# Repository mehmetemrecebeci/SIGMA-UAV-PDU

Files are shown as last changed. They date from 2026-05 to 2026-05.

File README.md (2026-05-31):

SIGMA UAV Power Distribution Unit (PDU), insansız hava araçlarında yüksek akım güç dağıtımını güvenli ve verimli şekilde gerçekleştirmek amacıyla geliştirilen çok katmanlı bir PCB tasarım projesidir. Tasarım sürecinde Altium Designer kullanılarak güç bütünlüğü, akım dönüş yolları ve elektromanyetik girişim (EMI) gereksinimleri dikkate alınmıştır.

Kart mimarisi; 24V, 12V, 9V ve 5V olmak üzere çoklu güç raylarından oluşmakta olup ESC'ler, servo sistemleri, görev bilgisayarları ve uçuş elektroniği için ayrılmış güç dağıtım altyapısı sağlamaktadır. Güç ve sinyal katmanları ayrıştırılarak düşük empedanslı akım yolları oluşturulmuş, sistem kararlılığı ve gürültü bağışıklığı artırılmıştır.

Proje kapsamında yüksek akım PCB yönlendirme teknikleri, geniş bakır alanlar, polygon tabanlı güç dağıtımı, via stitching uygulamaları ve çok katmanlı güç düzlemleri kullanılmıştır. Ayrıca güç dönüş akımlarının optimizasyonu, termal dağılım analizi ve EMI azaltma stratejileri üzerine çalışmalar gerçekleştirilmiştir.

Devam eden Rev2 geliştirme sürecinde tasarım, 6 katmanlı mimariye taşınarak güç dağıtım performansı, termal yönetim, EMI dayanımı ve üretilebilirlik kriterleri açısından iyileştirilmektedir.

Kullanılan Araçlar ve Teknolojiler:
• Altium Designer
• High Current PCB Design
• Power Distribution Architecture
• Multi-Rail Power Systems
• Grounding Strategy
• Power Integrity
• Thermal Design
• EMI/EMC Aware PCB Layout
• Via Stitching & Polygon Routing

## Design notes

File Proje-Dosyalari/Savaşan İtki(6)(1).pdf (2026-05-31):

Durumlar | Gereken T/W Oranı | Gerçeklşme Oranı | Gerçekleşme Süresi (dk) | Gereken Thrust | Harcanan Güç(W) | Harcanacak Toplam Güç (Wh) | Gereken Kapasite (mAh)
Cruise | 0.2 | 0.7 | 24.5 | 1300 | 166 | 67.78333333 | 3053.30
Maneuver | 0.5 | 0.2 | 7 | 3250 | 519 | 60.55 | 2727.48
High Effort | 1 | 0.1 | 3.5 | 6500 | 1364 | 79.56666667 | 3584.08
MTOW(g) | 6500 | | | | | İtki | 9364.86
Uçuş Süresi (dk) | 35 | | | | | İtki Güvenli | 11612.43243
Motor | Sunnysky x5220 KV380 X90 | | | | | Aviyonikler | 1102.083333
Bataryanın Nominal Voltajı(V) | 22.2 | | | | | Aviyonikler Güvenli | 1366.583333
Pervane Boyutu | 18*8 | | | | | Toplam | 10466.95
| | | | | | Toplam Güvenli | 12979.01577
Komponent | Komponent Adı | Ağırlık (Gram) | Maliyet
Motor | Sunnysky 5220 380KV | 486 | ₺11,560.00
İtki Bataryası | Profuse 15000mAh 15C 6S(solidstate) | 1065 | ₺17,000.00
Aviyonik Bataryası | Profuse 4200mAh 40C 2S | 234 | ₺1,774.00
İtki Batarya ESC | 120A ESC | 155 | ₺4,815.00
Aviyonik Batrya ESC | Hobbywing 8-15A ESC | 36 | ₺1,450.00
Pervane | 18*8 | 72 | ₺523.00
Toplam | | 1866 | ₺37,122.00

Aviyonik | Aviyoniğin Çalışmak İçin İhtiyaç Duyduğu Güç(W) | Wh | Volta j | Adet | Çekilecek Anlık Akım (A) | Görev Süresi(dk) | Toplam Kapasite
Pixhawk Cube Orange+ | 14 | 7 | 5 | 1 | 2.8 | 30 | 1400
RFD 868x | 2.5 | 1.25 | 5 | 1 | 1 | 30 | 500
R16F Alıcı | 0.25 | 0.125 | 5 | 1 | 0.05 | 30 | 25
Here 4 GPS | 3.33 | 1.665 | 5 | 1 | 0.666 | 30 | 333
Tf-mini plus Lidar | 0.05 | 0.025 | 5 | 1 | 0.11 | 30 | 55
mateksys ASPD-4525 | 0.3 | 0.15 | 6 | 1 | 0.05 | 30 | 25
Hitec HS-422 | 2 | 1 | 5 | 2 | 0.4 | 30 | 200
Emax ES08MD II | 5 | 2.5 | 5 | 5 | 1 | 30 | 500
Toplam Aviyonik | 27.43 | 13.715 | - | - | 6.076 | - | 3038
Toplam Aviyonik Güvenli | 3645.6
Arducam B0353 | 3 | 1.5 | 5 | 1 | 0.6 | 30 | 300
Jetson Orin NX 16 GB | 15 | 7.5 | 12 | 1 | 1.25 | 30 | 625
Ubiquiti Rocket 5AC LİTE | 8.5 | 4.25 | 24 | 1 | 0.354166667 | 30 | 177.0833333
Toplam İtki | 26.5 | 13.25 | - | - | 2.204166667 | 30 | 1102.083333
Toplam İtki Güvenli | 1366.583333

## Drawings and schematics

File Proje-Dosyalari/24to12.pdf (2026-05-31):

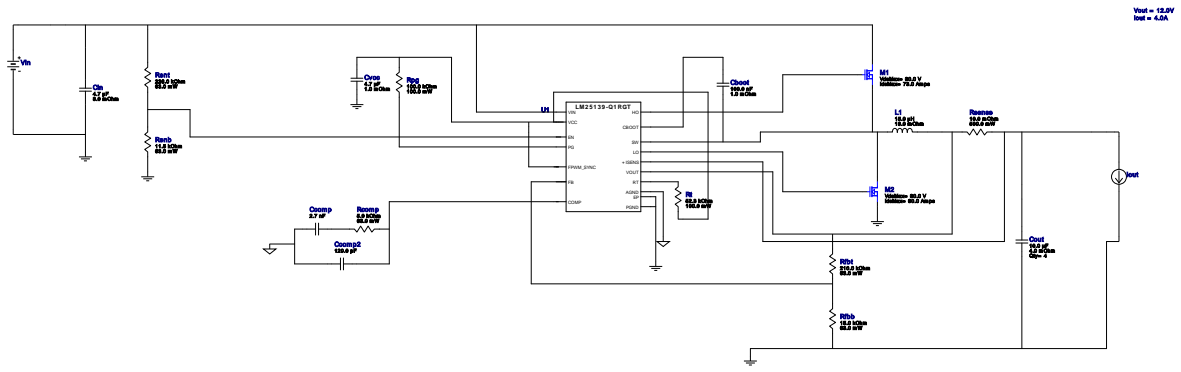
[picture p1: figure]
LM 2 5 1 3 9 -Q1 RGT VIN; FPWM_SYNC; AGND; COMP; VOUT; + ISENS; VCC; PGND; CBOOT EN; Cvcc 4.7 µF 1.0 m Ohm; Cout 10.0 µF; 4.0 m Ohm Qty= 4; Rpg 100.0 kOhm 100.0 m W; Rent 226.0 kOhm; Renb 11.5 kOhm 63.0 m W; M2 VdsMax= 30.0 V; IdsMax= 60.0 Am ps Rt 52.3 kOhm; 100.0 m W Ccom p; Rcom p; 5.9 kOhm 63.0 m W; Ccom p2 120.0 pF; Rfbb 15.0 kOhm 63.0 m W; Rfbt 210.0 kOhm; 19.0 m Ohm; Rsense; 10.0 m Ohm 500.0 m W; Vout = 12.0V Iout = 4.0A; Cin 4.7 µF 3.0 m Ohm; Cboot 100.0 nF; 1.0 m Ohm; M1 VdsMax= 30.0 V IdsMax= 73.0 Am ps; Vin; Iout

Copyright © 2026, Texas Instruments Incorporated | 1 | ti.com/webench

WEBENCH®
Design Report LM25139QRGTRQ1 : LM25139QRGTRQ1 23V-24V to 12.00V @ 4A March 28, 2026 08:51:25 GMT-05:00

## WEBENCH ® Design Report

Design : 13 LM25139QRGTRQ1
LM25139QRGTRQ1 23V-24V to 12.00V @ 4A

VinMin = 23.0V
VinMax = 24.0V
Vout = 12.0V
Iout = 4.0A

Device = LM25139QRGTRQ1
Topology = Buck
Created = 2026-03-28 08:48:47.775 BOM Cost = $2.57
BOM Count = 21
Total Pd = 1.12W

### Design Alerts

Component Selection Information
The LM25139-Q1 is qualified for Automotive applications. All passives and other components selected in this design may not be qualified for Automotive applications. The user is required to verify that all components in the design meet the qualification and safety requirements for their specific application.Please enter Enable UVLO Start Threshold greater than Enable 1.1* UVLO Stop Threshold. UVLO Start Threshold is assumed as 23.0V to avoid invalid results.

## Electrical BOM

Name | Manufacturer | Part Number | Properties | Qty Price | Footprint
Cboot | MuRata | GRM155R71A104KA01D (http://search.murata.co.jp/Ceramy/PnsearchViewAction.do) Series= X7R | Cap= 100.0 nF ESR= 1.0 mOhm VDC= 10.0 V IRMS= 0.0 A
1 | $0.01
| | | | | 0402 3 mm²
Ccomp | MuRata | GRM1885C1H272JA01J (http://www.murata.com/products/catalog/pdf/c02e.pdf) Series= C0G/NP0

Cap= 2.7 nF
VDC= 50.0 V
IRMS= 0.0 A

1 $0.02
0603 5 mm²
Ccomp2 | Taiyo Yuden | UMK105CG121JV-F (http://media.digikey.com/pdf/Data%20Sheets/Taiyo%20Yuden%20PDFs%20URL%20links/Standard%20Multilayer%20Ceramic%20Caps.pdf) Series= C0G/NP0

Cap= 120.0 pF
VDC= 50.0 V
IRMS= 0.0 A

1 $0.01
0402 3 mm²
Cin | MuRata | GRM31CR71H475KA12L (http://search.murata.co.jp/Ceramy/PnsearchViewAction.do) Series= X7R

Cap= 4.7 uF
ESR= 3.0 mOhm
VDC= 50.0 V
IRMS= 4.98 A

1 $0.10
1206 11 mm²
Cout | MuRata | GRM31CR71E106KA12L Series= X7R

Cap= 10.0 uF
ESR= 4.0 mOhm
VDC= 25.0 V
IRMS= 6.0 A

4 $0.06
1206_180 11 mm²
Cvcc | Taiyo Yuden | LMK212B7475KG-T (http://www.yuden.co.jp/ut/product/pdf/djmk%5Fe.pdf) Series= X7R

Cap= 4.7 uF
ESR= 1.0 mOhm
VDC= 10.0 V
IRMS= 0.0 A

1 $0.04
0805 7 mm²
L1 | Coilcraft | MSS1210-153MEB (http://www.coilcraft.com/pdfs/mss1210.pdf) | L= 15.0 µH 19.0 mOhm
1 | $0.81

MSS1210 204 mm²

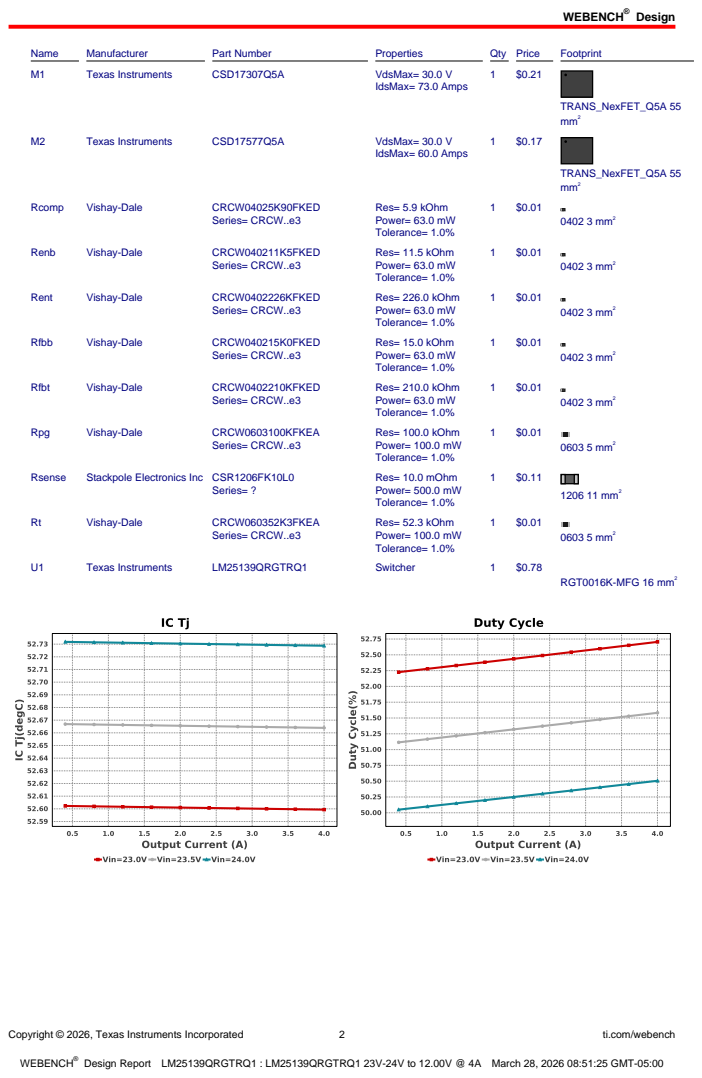
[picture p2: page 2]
Design; Copyright © 2026, Texas Instruments Incorporated; ti.com/webench; Name; Manufacturer; Part Number; Properties; Qty Price; Footprint; Texas Instruments; CSD17307Q5A; VdsMax= 30.0 V; IdsMax= 73.0 Amps; TRANS_NexFET_Q5A 55 mm²; CSD17577Q5A; IdsMax= 60.0 Amps; Rcomp; Vishay-Dale; CRCW04025K90FKED; Series= CRCW..e3; Res= 5.9 kOhm Power= 63.0 mW Tolerance= 1.0%; 0402 3 mm²; Renb; CRCW040211K5FKED; Res= 11.5 kOhm Power= 63.0 mW Tolerance= 1.0%; Rent; CRCW0402226KFKED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

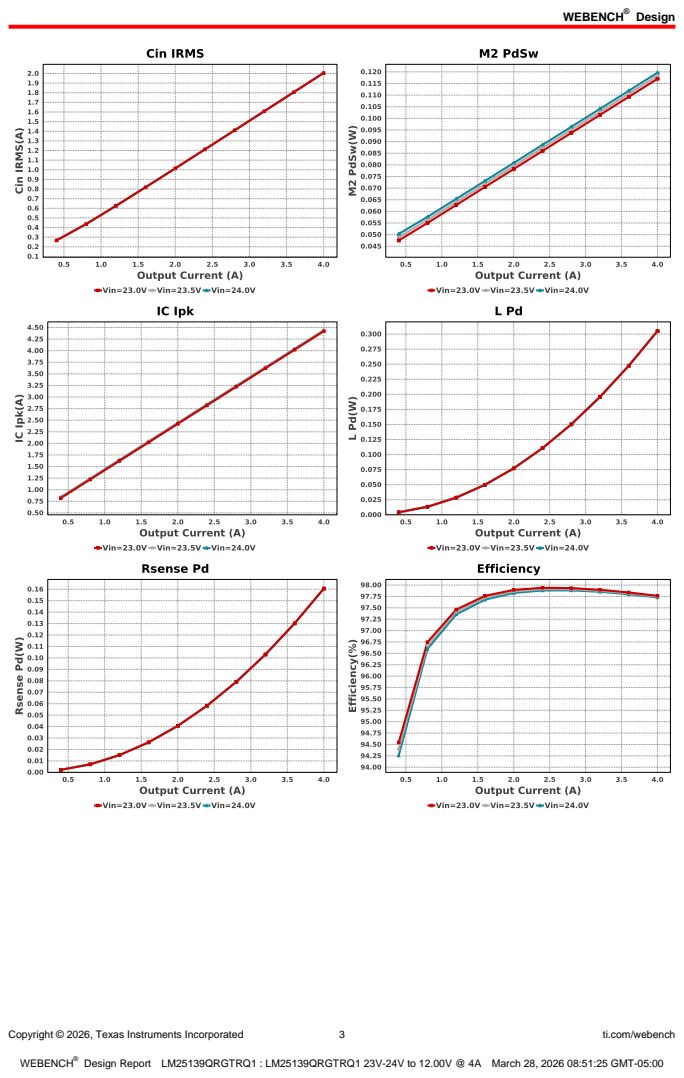
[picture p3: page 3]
Copyright © 2026, Texas Instruments Incorporated; ti.com/webench

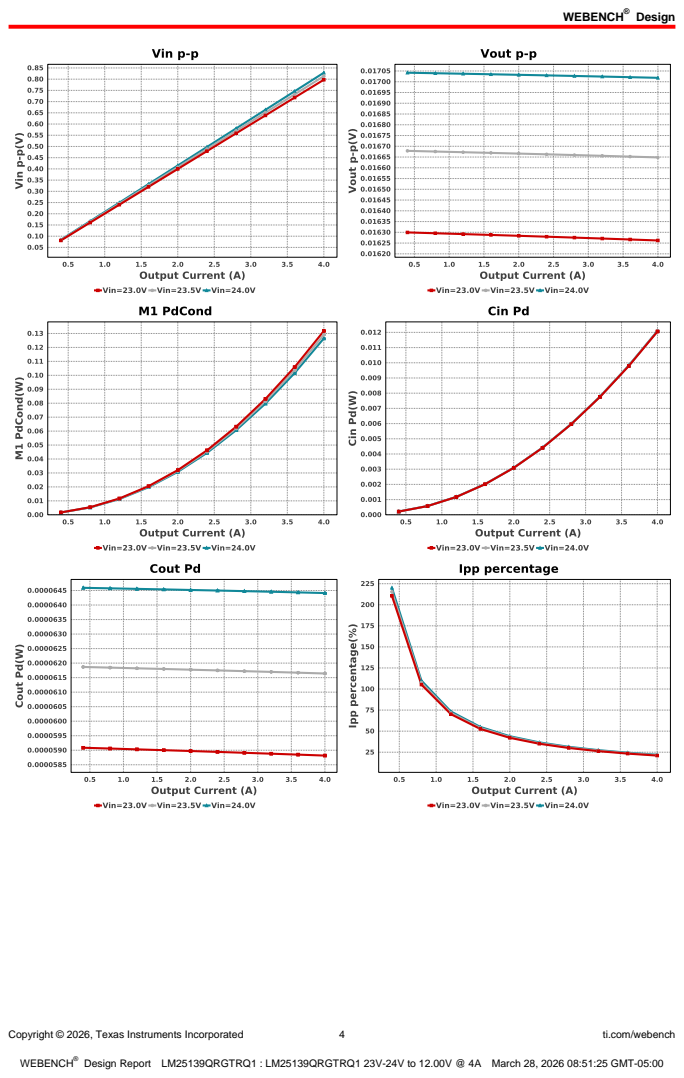
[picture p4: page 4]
Copyright © 2026, Texas Instruments Incorporated; ti.com/webench

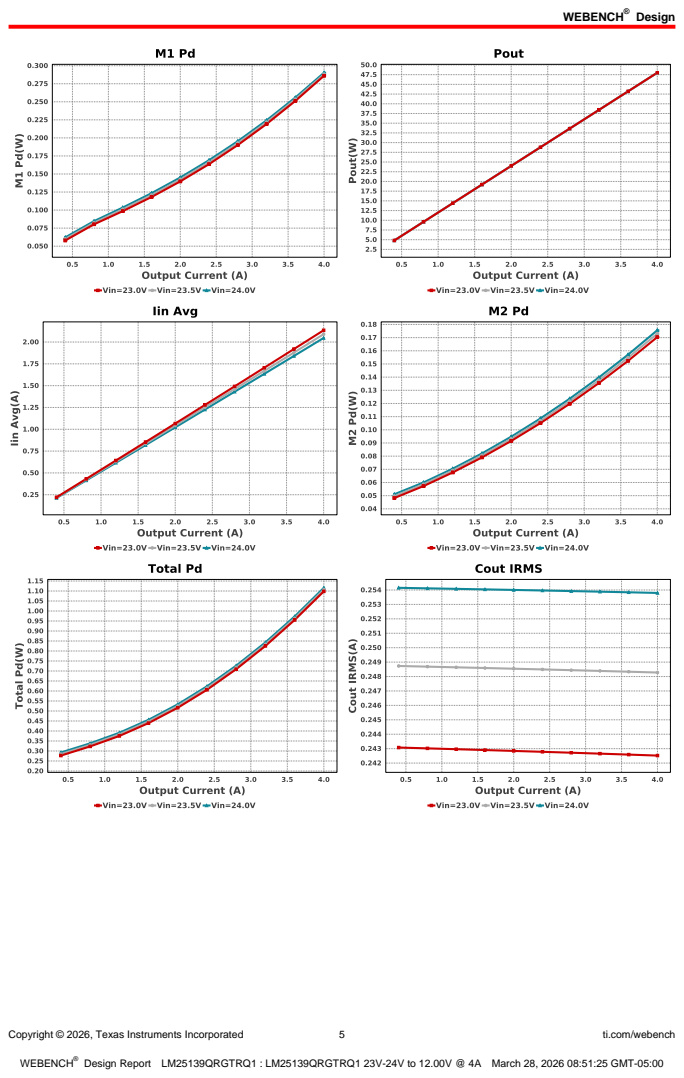
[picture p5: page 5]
Copyright © 2026, Texas Instruments Incorporated; ti.com/webench

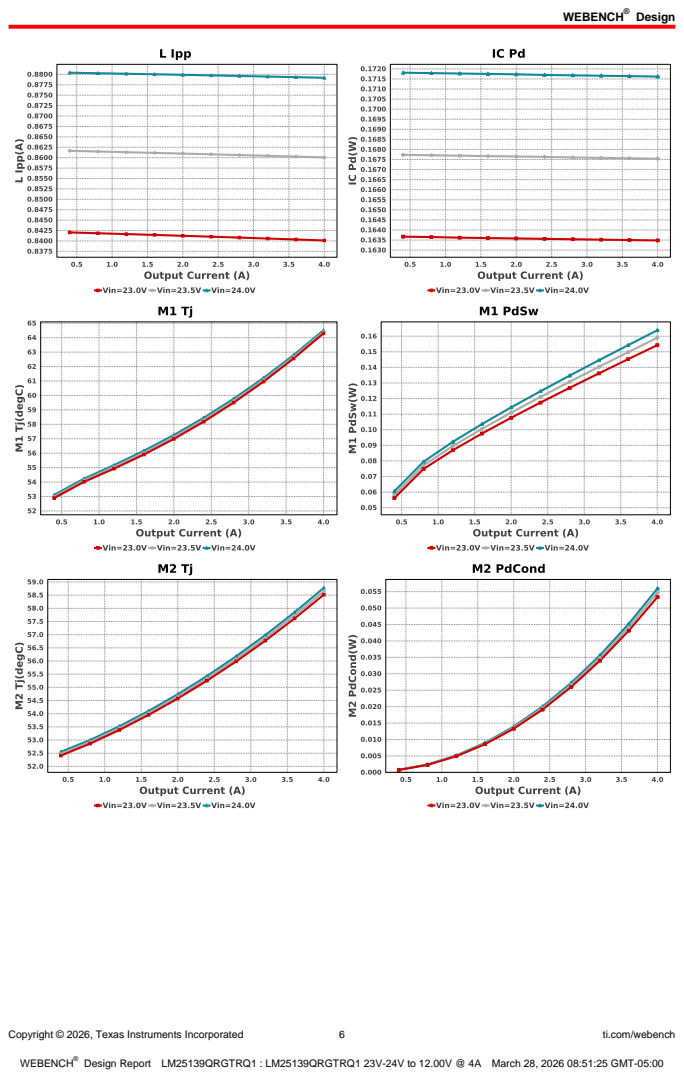
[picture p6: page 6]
Copyright © 2026, Texas Instruments Incorporated; ti.com/webench

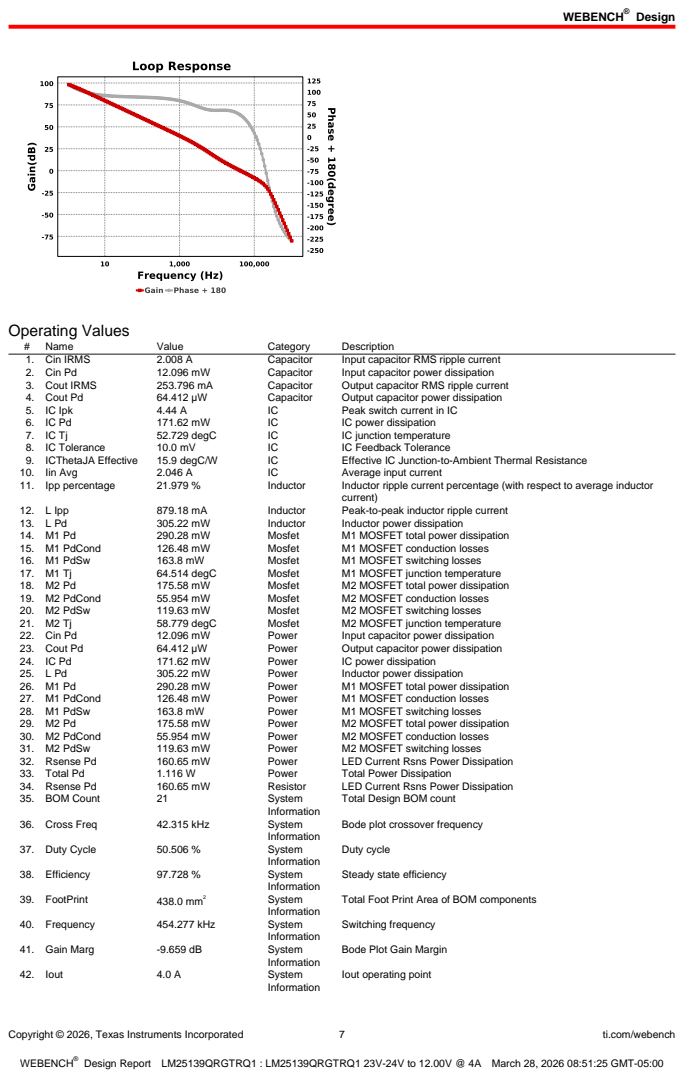
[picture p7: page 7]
Copyright © 2026, Texas Instruments Incorporated; ti.com/webench; Operating Values; Name; Value; Category; Description; 1. Cin IRMS; Capacitor; Input capacitor RMS ripple current; 2. Cin Pd; Input capacitor power dissipation; 3. Cout IRMS; Output capacitor RMS ripple current; 4. Cout Pd; Output capacitor power dissipation; 5. IC Ipk; Peak switch current in IC; IC power dissipation; 52.729 degC; IC junction temperature; 8. IC Tolerance; IC Feedback Tolerance; 9. ICThetaJA Effective; 15.9 degC/W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

Total Design BOM count

Bode plot crossover frequency

Steady state efficiency

Total Foot Print Area of BOM components

Bode Plot Gain Margin

Iout operating point

Copyright © 2026, Texas Instruments Incorporated | 8 | ti.com/webench
# | Name | Value | Category | Description
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

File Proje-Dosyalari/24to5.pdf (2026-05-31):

## WEBENCH ® Design Report

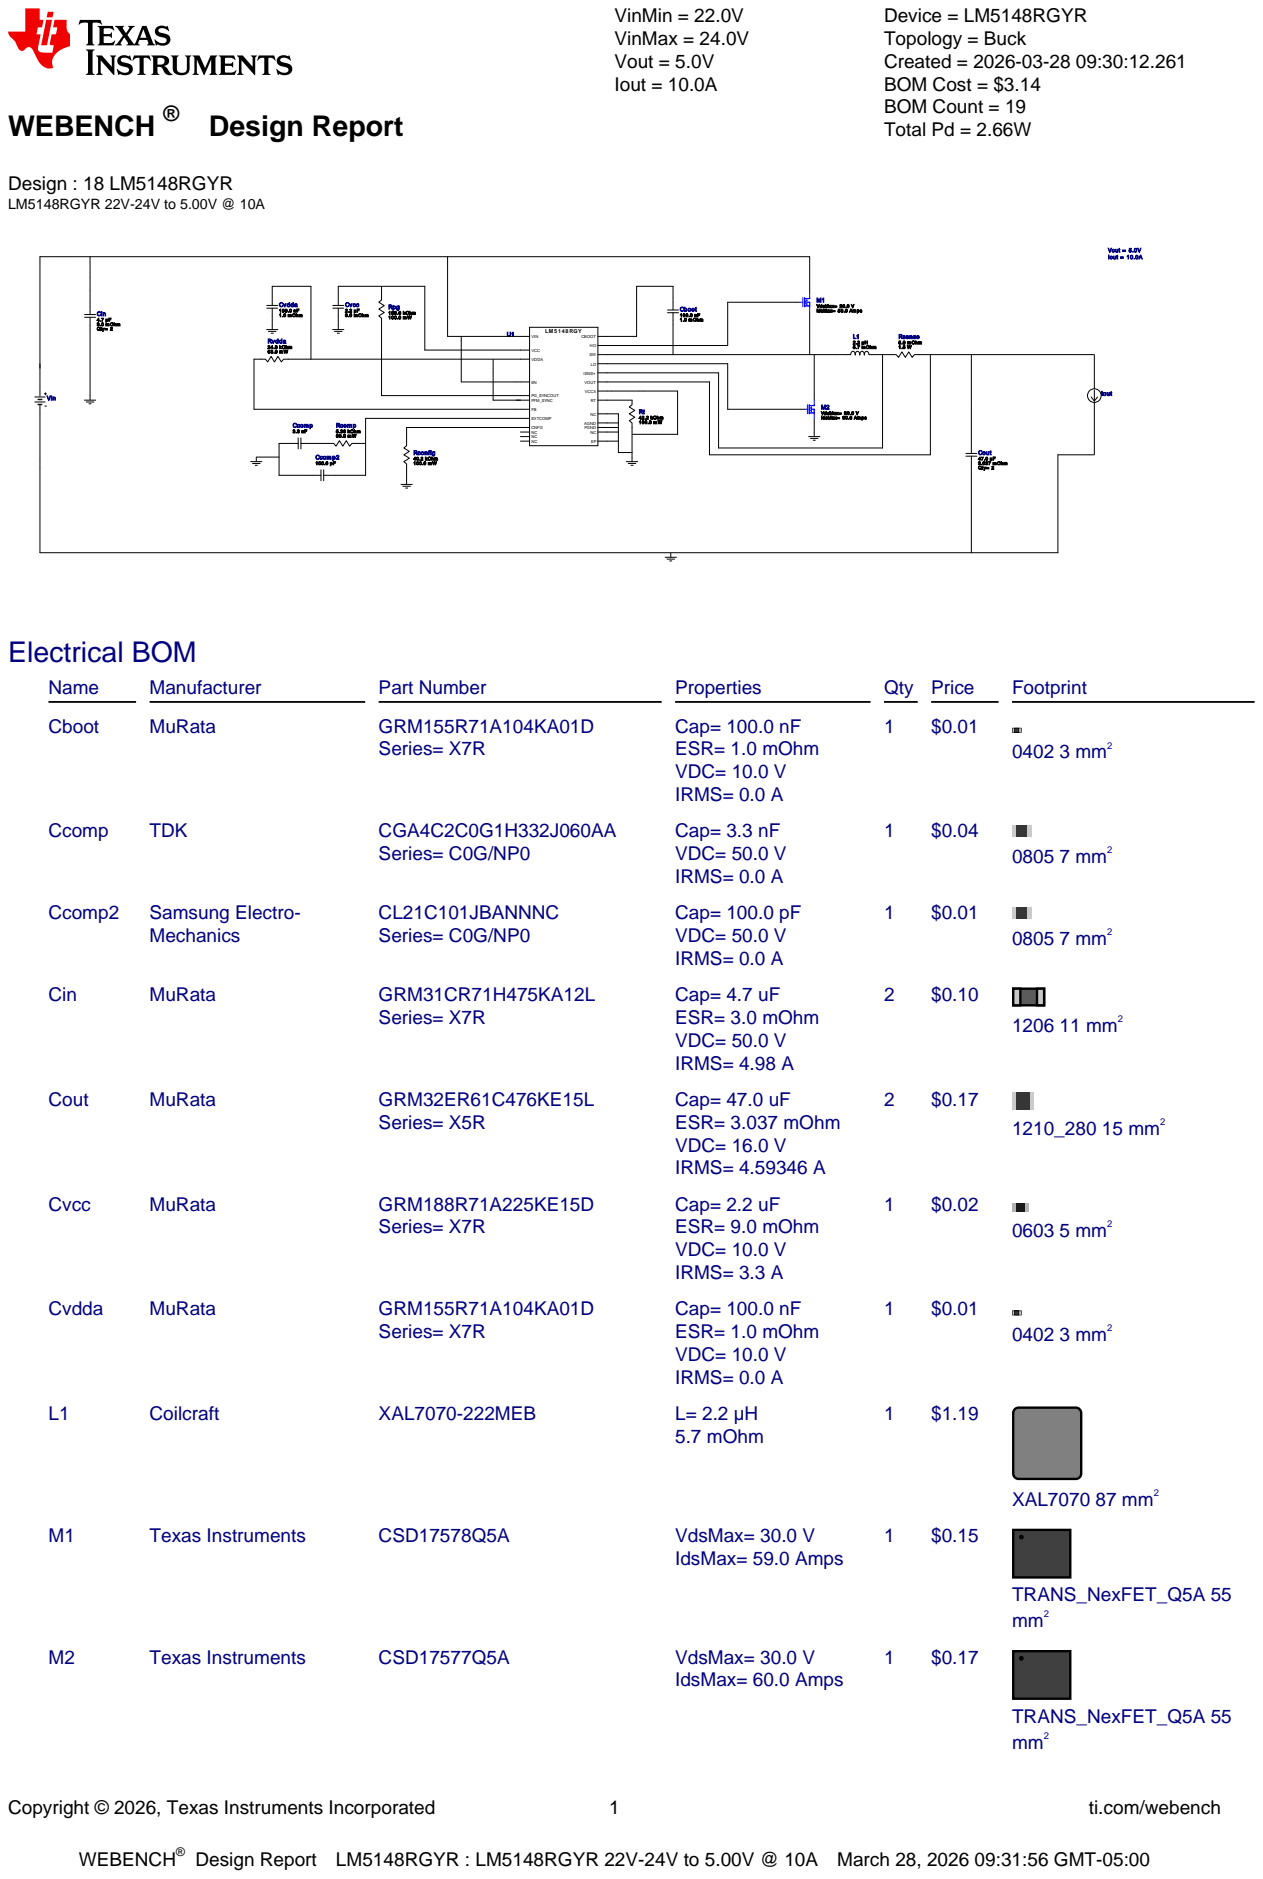
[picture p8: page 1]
Copyright © 2026, Texas Instruments Incorporated; ti.com/webench; WEBENCH®; Design : 18 LM5148RGYR LM5148RGYR 22V-24V to 5.00V @ 10A; VinMin = 22.0V VinMax = 24.0V Vout = 5.0V Iout = 10.0A; Device = LM5148RGYR Topology = Buck Created = 2026-03-28 09:30:12.261 BOM Cost = $3.14 BOM Count = 19 Total Pd = 2.66W; Cvcc 2.2 µF; 9.0 m Ohm; Cboot 100.0 nF; 1.0 m Ohm; Cvdda 100.0 nF 1.0 m Ohm; Ccom p2 100.0 pF; Ccom p; Rcom p; 5.36 kOhm 63.0 m W; Cout 47.0 µF; 3.037 m Ohm Qty= 2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

Design Report LM5148RGYR : LM5148RGYR 22V-24V to 5.00V @ 10A March 28, 2026 09:31:56 GMT-05:00

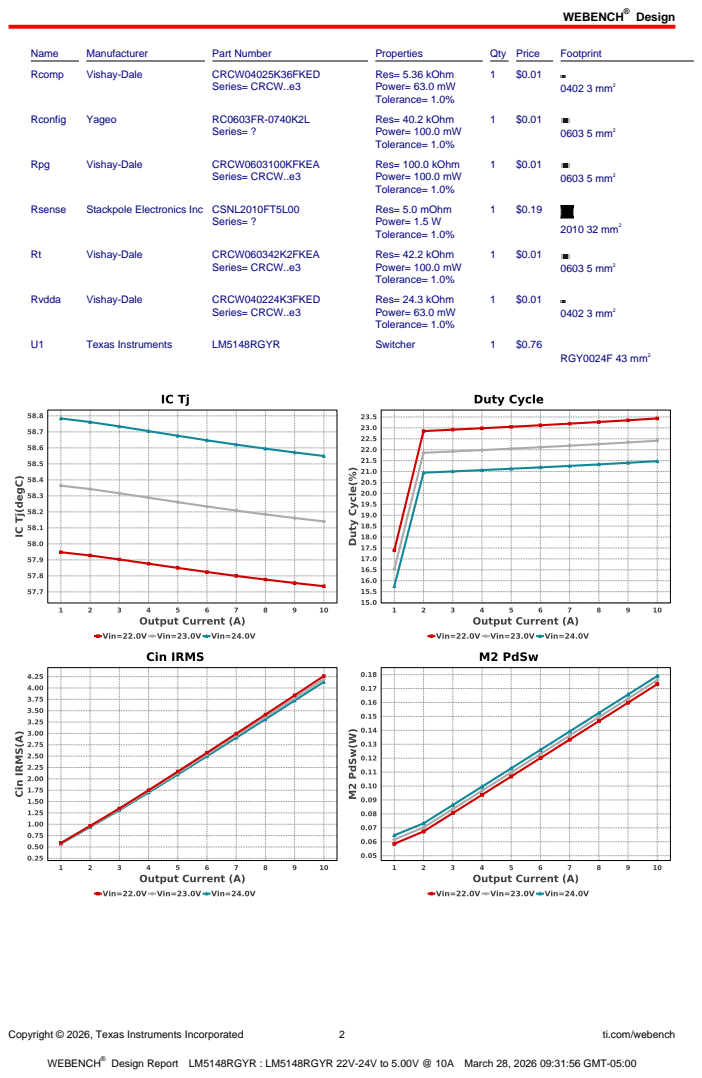
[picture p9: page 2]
Design; Copyright © 2026, Texas Instruments Incorporated; ti.com/webench; Name; Manufacturer; Part Number; Properties; Qty Price; Footprint; Rcomp; Vishay-Dale; CRCW04025K36FKED; Series= CRCW..e3; Res= 5.36 kOhm Power= 63.0 mW Tolerance= 1.0%; 0402 3 mm²; Rconfig; Yageo; Series= ?; Res= 40.2 kOhm Power= 100.0 mW Tolerance= 1.0%; 0603 5 mm²; Rpg; CRCW0603100KFKEA; Res= 100.0 kOhm Power= 100.0 mW Tolerance= 1.0%; Rsense; Stackpole Electronics Inc CSNL2010FT5L00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

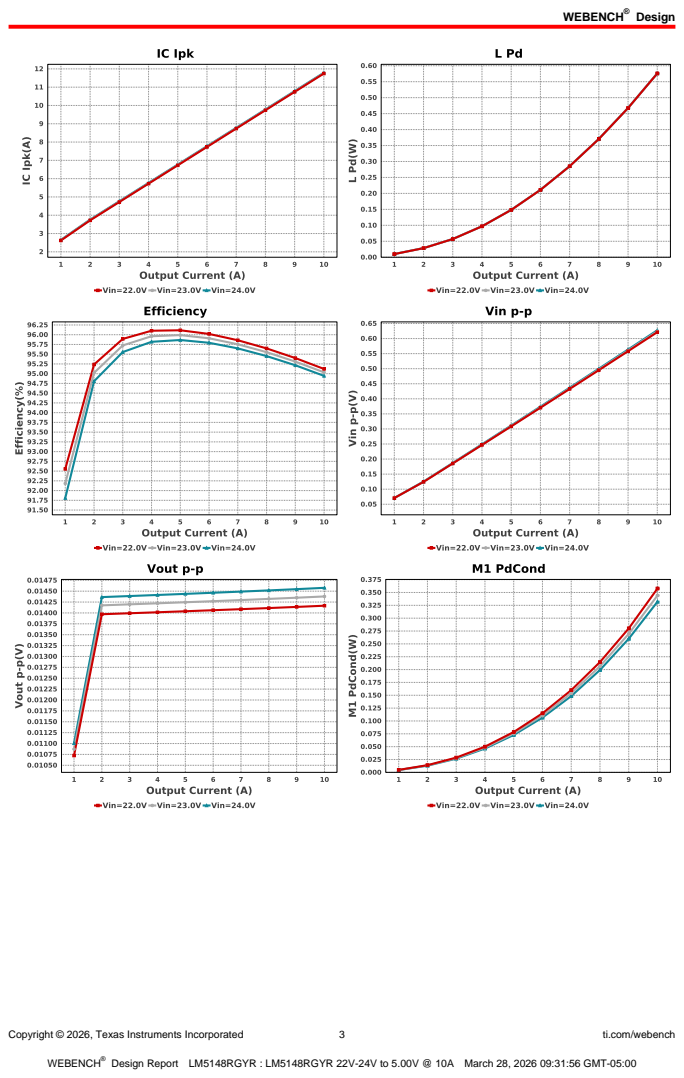
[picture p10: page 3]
Copyright © 2026, Texas Instruments Incorporated; ti.com/webench

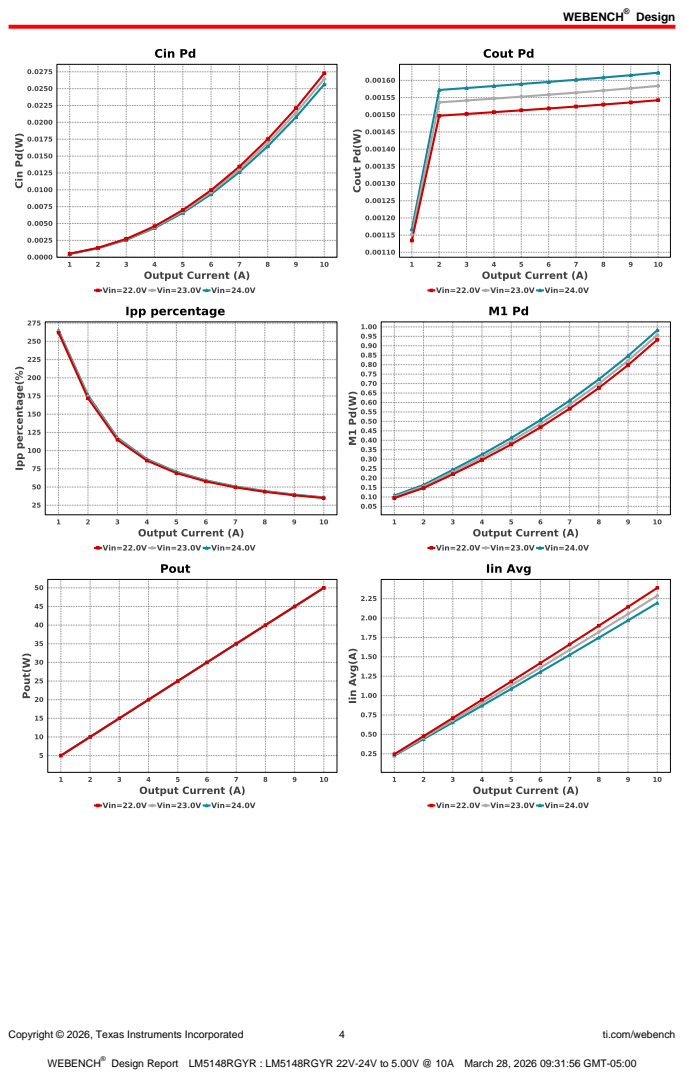
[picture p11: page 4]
Copyright © 2026, Texas Instruments Incorporated; ti.com/webench

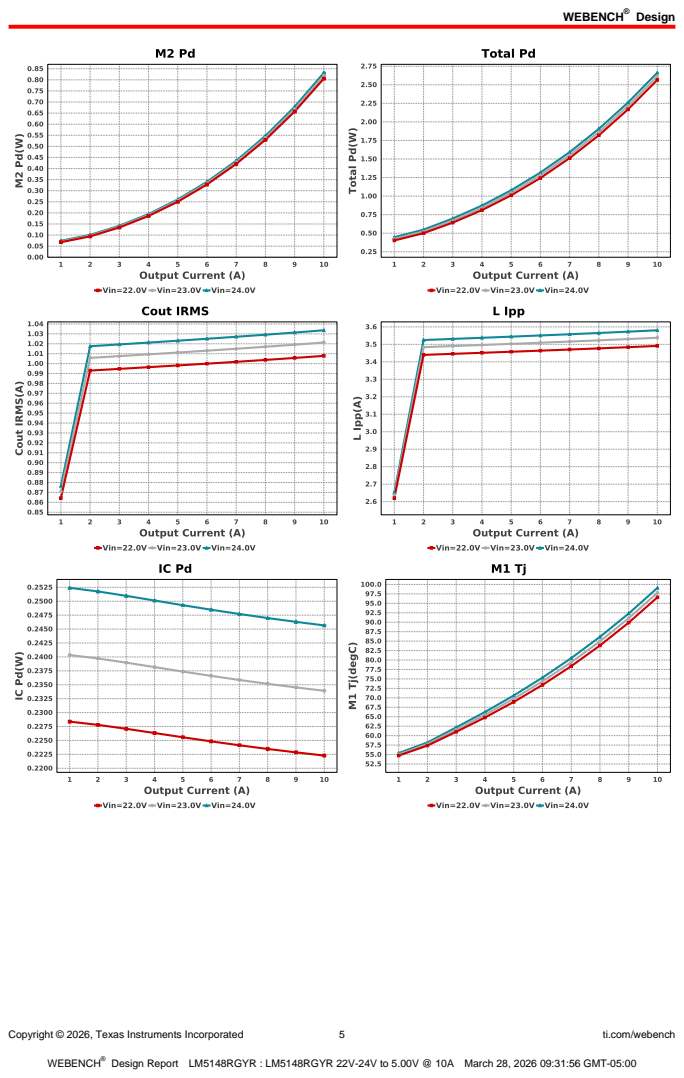
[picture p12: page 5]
Copyright © 2026, Texas Instruments Incorporated; ti.com/webench

Copyright © 2026, Texas Instruments Incorporated; ti.com/webench; Operating Values; Name; Value; Category; Description; 1. Cin IRMS; Capacitor; Input capacitor RMS ripple current; 2. Cin Pd; Input capacitor power dissipation; 3. Cout IRMS; Output capacitor RMS ripple current; 4. Cout Pd; Output capacitor power dissipation; 5. IC Ipk; Peak switch current in IC; IC power dissipation; 58.549 degC; IC junction temperature; 8. IC Tolerance; IC Feedback Tolerance; 9. ICThetaJA Effective; 34.8 degC/W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

Copyright © 2026, Texas Instruments Incorporated | 7 | ti.com/webench
# | Name | Value | Category | Description

11. Ipp percentage | 35.806 % | Inductor | Inductor ripple current percentage (with respect to average inductor
| | | | current)
12. L Ipp | 3.581 A | Inductor | Peak-to-peak inductor ripple current
13. L Pd | 576.09 mW | Inductor | Inductor power dissipation
14. M1 Pd | 982.06 mW | Mosfet | M1 MOSFET total power dissipation
15. M1 PdCond | 331.98 mW | Mosfet | M1 MOSFET conduction losses
16. M1 PdSw | 650.09 mW | Mosfet | M1 MOSFET switching losses
17. M1 Tj | 99.103 degC | Mosfet | M1 MOSFET junction temperature
18. M2 Pd | 831.75 mW | Mosfet | M2 MOSFET total power dissipation
19. M2 PdCond | 652.74 mW | Mosfet | M2 MOSFET conduction losses
20. M2 PdSw | 179.01 mW | Mosfet | M2 MOSFET switching losses
21. M2 Tj | 91.588 degC | Mosfet | M2 MOSFET junction temperature
22. Cin Pd | 25.641 mW | Power | Input capacitor power dissipation
23. Cout Pd | 1.622 mW | Power | Output capacitor power dissipation
24. IC Pd | 245.66 mW | Power | IC power dissipation
25. L Pd | 576.09 mW | Power | Inductor power dissipation
26. M1 Pd | 982.06 mW | Power | M1 MOSFET total power dissipation
27. M1 PdCond | 331.98 mW | Power | M1 MOSFET conduction losses
28. M1 PdSw | 650.09 mW | Power | M1 MOSFET switching losses
29. M2 Pd | 831.75 mW | Power | M2 MOSFET total power dissipation
30. M2 PdCond | 652.74 mW | Power | M2 MOSFET conduction losses
31. M2 PdSw | 179.01 mW | Power | M2 MOSFET switching losses
32. Total Pd | 2.663 W | Power | Total Power Dissipation
33. BOM Count | 19 | System
| | | Information | Total Design BOM count
34. Cross Freq | 49.472 kHz | System
| | | Information | Bode plot crossover frequency
35. Duty Cycle | 21.477 % | System
| | | Information | Duty cycle
36. Efficiency | 94.944 % | System
| | | Information | Steady state efficiency
37. FootPrint | 367.0 mm² | System
| | | Information | Total Foot Print Area of BOM components
38. Frequency | 512.295 kHz | System
| | | Information | Switching frequency
39. Gain Marg | -13.777 dB | System
| | | Information | Bode Plot Gain Margin
40. Iout | 10.0 A | System
| | | Information | Iout operating point
41. Iout transient step used
| for Cout calculations | 5.0 A | System Information | Custom Transient current step requirement that was used for Cout selection (A).
42. Low Freq Gain | 94.908 dB | System
| | | Information | Gain at 1Hz
43. Mode | CCM | System
| | | Information | Conduction Mode
44. Overshoot Value | 86.761 mV | System
| | | Information | Theoretical Vout Overshoot Value
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

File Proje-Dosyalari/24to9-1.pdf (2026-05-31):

## WEBENCH ® Design Report

Copyright © 2026, Texas Instruments Incorporated; ti.com/webench; WEBENCH®; Design : 21 TPS563300DRLR TPS563300DRLR 24V-24V to 9.00V @ 3A; VinMin = 24.0V VinMax = 24.0V Vout = 9.0V Iout = 1.5A; Device = TPS563300DRLR Topology = Buck Created = 2026-04-26 13:41:08.597 BOM Cost = $1.31 BOM Count = 8 Total Pd = 0.45W; TPS5 6 3 3 0 0 DRL; VIN; GND; BST; Cinx 100.0 nF; 29.6 m Ohm; Cout 47.0 µF; 3.037 m Ohm; Vout = 9.0V Iout = 1.5A; L1 10.0 µH 21.0 m Ohm; Rfbb 10.0 kOhm 63.0 m W; Rfbt 102.0 kOhm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

Design Report TPS563300DRLR : TPS563300DRLR 24V-24V to 9.00V @ 3A April 26, 2026 13:42:25 GMT-05:00

Design; Copyright © 2026, Texas Instruments Incorporated; ti.com/webench

Copyright © 2026, Texas Instruments Incorporated; ti.com/webench

Copyright © 2026, Texas Instruments Incorporated; ti.com/webench

Copyright © 2026, Texas Instruments Incorporated; ti.com/webench; Operating Values; Name; Value; Category; Description; 1. Cin IRMS; Capacitor; Input capacitor RMS ripple current; 2. Cin Pd; Input capacitor power dissipation; 3. Cout IRMS; Output capacitor RMS ripple current; 4. Cout Pd; Output capacitor power dissipation; 5. IC Ipk; Peak switch current in IC; IC power dissipation; 74.18 degC; IC junction temperature; 8. IC Tolerance; IC Feedback Tolerance; 9. ICThetaJA Effective; 60.25 degC/W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

Total Design BOM count

Bode plot crossover frequency

Steady state efficiency

Total Foot Print Area of BOM components

Bode Plot Gain Margin

26. Inductor ripple current
requirement used for
Inductor selection

Custom Inductor ripple current (% of average inductor current)
requirement used for Inductor selection

Iout operating point

28. Iout transient step used
for Cout calculations

Custom Transient current step requirement that was used for Cout
selection (A).
Gain at 1Hz

Theoretical Vout Overshoot Value

Bode Plot Phase Margin

Total output power

Total BOM Cost

Copyright © 2026, Texas Instruments Incorporated | 6 | ti.com/webench
# | Name | Value | Category | Description

35. Undershoot Value | 59.319 mV | System
| | | Information | Theoretical Vout Undershoot Value
36. Vin | 24.0 V | System
| | | Information | Vin operating point
37. Vin p-p | 184.65 mV | System
| | | Information | Peak-to-peak input voltage
38. Vout | 9.0 V | System
| | | Information | Operational Output Voltage
39. Vout Actual | 8.96 V | System
| | | Information | Vout Actual calculated based on selected voltage divider resistors
40. Vout Ripple
| requirement used for Cout calculations | 1.0 % | System Information | Custom maximum output ripple requirement that was used for Cout selection(% of Vout).
41. Vout Tolerance | 3.877 % | System
| | | Information | Vout Tolerance based on IC Tolerance (no load) and voltage divider resistors if applicable
42. Vout p-p | 15.075 mV | System
| | | Information | Peak-to-peak output ripple voltage
43. Vout transient
| requirement used for Cout calculations | 3.0 % | System Information | Custom Transient voltage change requirement that was used for Cout selection (% of Vout).

## Design Inputs

Name | Value | Description
Iout | 1.5 | Maximum Output Current
VinMax | 24.0 | Maximum input voltage
VinMin | 24.0 | Minimum input voltage
Vout | 9.0 | Output Voltage
| base_pn | | TPS563300 | Base Product Number
source | DC | Input Source Type
Ta | 50.0 | Ambient temperature


Copyright © 2026, Texas Instruments Incorporated | 7 | ti.com/webench

## Assembly

## Component Testing

Some published data on components in datasheets such as Capacitor ESR and Inductor DC resistance is based on conservative values that will guarantee that the components always exceed the specification. For design purposes it is usually better to work with typical values. Since this data is not always available it is a good practice to measure the Capacitance and ESR values of Cin and Cout, and the inductance and DC resistance of L1 before assembly of the board. Any large discrepancies in values should be electrically simulated in WEBENCH to check for instabilities and thermally simulated in WebTHERM to make sure critical temperatures are not exceeded.
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

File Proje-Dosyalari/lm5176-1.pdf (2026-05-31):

## WEBENCH ® Design Report

Copyright © 2026, Texas Instruments Incorporated; ti.com/webench; WEBENCH®; Design : 20 LM5176PWPR LM5176PWPR 12V-45V to 24.00V @ 5A; VinMin = 12.0V VinMax = 45.0V Vout = 24.0V Iout = 5.0A; M2 VdsMax= 100.0 V IdsMax= 50.0 Am ps; Cboot2 100.0 nF 50.0 m Ohm; Rf 10.0 Ohm; _LDRV2_2 Rcom p; 5.36 kOhm 63.0 m W; _CSG_2; Rpg 10.0 kOhm 100.0 m W; Ccom p 15.0 nF; 216.2 m Ohm; Ccom p2; Dboot1 VF@Io= 500.0 m V VRRM= 54.0 V; Rsense 8.0 m Ohm 2.0 W; Dboot2 VF@Io= 510.0 m V; VIN; VINSNS; MODE; DITH; RT_SYNC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

Device = LM5176PWPR
Topology = Buck_Boost
Created = 2026-04-26 13:01:12.694
BOM Cost = NA
BOM Count = 57
Total Pd = 2.14W

IdsMax= 59.0 Am ps Df VF@Io= 500.0 m V

VRRM= 40.0 V LM 5 1 7 6 PW P

Design Report LM5176PWPR : LM5176PWPR 12V-45V to 24.00V @ 5A April 26, 2026 13:03:16 GMT-05:00

Design

Copyright © 2026, Texas Instruments Incorporated | 2 | ti.com/webench
Name | Manufacturer | Part Number | Properties | Qty Price | Footprint
Cin | TDK | C5750X7S2A106M230KB (http://www.tdk.com/pdf/mid%5Fvolt%5FB11.pdf) Series= X7S | Cap= 10.0 uF ESR= 5.0 mOhm VDC= 100.0 V IRMS= 6.45 A
3 | $0.76
| | | | | 2220 54 mm²
Cout | Panasonic | 35SVPF22M Series= SVPF | Cap= 22.0 uF ESR= 35.0 mOhm VDC= 35.0 V IRMS= 2.6 A
2 | $0.57
| | | | | CAPSMT_62_F61 74 mm²
Coutx | Taiyo Yuden | MSASU21GBB5475KTNA01 (https://ds.yuden.co.jp/TYCOMPAS/ut/detail?pn%3DMSASU21GBB5475KTNA01%26u%3DM) Series= X5R | Cap= 4.7 uF ESR= 10.306 mOhm VDC= 50.0 V IRMS= 2.1789 A
5 | $0.09
| | | | | 0805 7 mm²
Coutx2 | Taiyo Yuden | MSASU21GBB5475KTNA01 (https://ds.yuden.co.jp/TYCOMPAS/ut/detail?pn%3DMSASU21GBB5475KTNA01%26u%3DM) Series= X5R

Cap= 4.7 uF
ESR= 10.306 mOhm
VDC= 50.0 V
IRMS= 2.1789 A

5 $0.09
0805 7 mm²
Coutx3 | Taiyo Yuden | MSASU21GBB5475KTNA01 (https://ds.yuden.co.jp/TYCOMPAS/ut/detail?pn%3DMSASU21GBB5475KTNA01%26u%3DM) Series= X5R

Cap= 4.7 uF
ESR= 10.306 mOhm
VDC= 50.0 V
IRMS= 2.1789 A

5 $0.09
0805 7 mm²
Cslope | Samsung Electro- Mechanics | CL10C331JB8NNNC (http://www.samsungsem.com/servlet/FileDownload?type%3Dspec%26file%3DCL10C331JB8NNNC.pdf) Series= C0G/NP0

Cap= 330.0 pF
VDC= 50.0 V
IRMS= 0.0 A

1 $0.01
0603 5 mm²
Css | Kemet | C0603C153J3GACTU (http://www.kemet.com/docfinder?Partnumber%3DC0603C153J3GACTU) Series= C0G/NP0

Cap= 15.0 nF
VDC= 25.0 V
IRMS= 0.0 A

1 $0.09
0603 5 mm²
Cvcc | Taiyo Yuden | EMK107B7105KA-T (http://www.yuden.co.jp/ut/product/pdf/djmk%5Fe.pdf) Series= X7R

Cap= 1.0 uF
ESR= 1.0 mOhm
VDC= 16.0 V
IRMS= 0.0 A

1 $0.01
0603 5 mm²
Dboot1 | CUSTOM | CUSTOM | VF@Io= 500.0 mV VRRM= 54.0 V
1 | NA
CUSTOM 0 mm²
Dboot2 | Comchip Technology | CDBK0540-HF (http://www.comchiptech.com/cms/UserFiles/CDBK0540%2DHF%2DRevB797997.pdf) | VF@Io= 510.0 mV VRRM= 40.0 V
1 | $0.07
SOD-123F 12 mm²
Df | CUSTOM | CUSTOM | VF@Io= 500.0 mV VRRM= 54.0 V
1 | NA
CUSTOM 0 mm²
L1 | Coilcraft | XAL1010-562MEB (http://www.coilcraft.com/pdfs/xal1010.pdf) | L= 5.6 µH 6.3 mOhm
1 | $1.71

XAL1010 160 mm²
M1 | Texas Instruments | CSD19534Q5A (http://www.ti.com/lit/ds/symlink/csd19534q5a.pdf) | VdsMax= 100.0 V IdsMax= 50.0 Amps
1 | $0.28

TRANS_NexFET_Q5A 55
mm²
M2 | Texas Instruments | CSD19534Q5A (http://www.ti.com/lit/ds/symlink/csd19534q5a.pdf) | VdsMax= 100.0 V IdsMax= 50.0 Amps
1 | $0.28

TRANS_NexFET_Q5A 55
mm²
M3 | Texas Instruments | CSD17578Q5A (http://www.ti.com/lit/ds/symlink/csd17578q5a.pdf) | VdsMax= 30.0 V IdsMax= 59.0 Amps
1 | $0.15

TRANS_NexFET_Q5A 55
mm²
M4 | Texas Instruments | CSD18531Q5A (http://www.ti.com/lit/ds/symlink/csd18531q5a.pdf) | VdsMax= 60.0 V IdsMax= 100.0 Amps
1 | $0.45

TRANS_NexFET_Q5A 55
mm²
Rcomp | Vishay-Dale | CRCW04025K36FKED (http://www.vishay.com/docs/20035/dcrcwe3.pdf) Series= CRCW..e3 | Res= 5.36 kOhm Power= 63.0 mW Tolerance= 1.0%
1 | $0.01
0402 3 mm²

Copyright © 2026, Texas Instruments Incorporated; ti.com/webench; Name; Manufacturer; Part Number; Properties; Qty Price; Footprint; Rcsg; Vishay-Dale; CRCW0603100RFKEA; Series= CRCW..e3; Res= 100.0 Ohm Power= 100.0 mW Tolerance= 1.0%; 0603 5 mm²; Rcsp; Yageo; Series= ?; Res= 10.0 Ohm Power= 100.0 mW Tolerance= 1.0%; Rfbb; Res= 20.0 kOhm Power= 100.0 mW Tolerance= 1.0%; Rfbt; Res= 576.0 kOhm Power= 100.0 mW Tolerance= 1.0%; Rmode; Res= 93.1 kOhm Power= 100.0 mW Tolerance= 1.0%; Rpg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

Copyright © 2026, Texas Instruments Incorporated; ti.com/webench

Copyright © 2026, Texas Instruments Incorporated; ti.com/webench
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

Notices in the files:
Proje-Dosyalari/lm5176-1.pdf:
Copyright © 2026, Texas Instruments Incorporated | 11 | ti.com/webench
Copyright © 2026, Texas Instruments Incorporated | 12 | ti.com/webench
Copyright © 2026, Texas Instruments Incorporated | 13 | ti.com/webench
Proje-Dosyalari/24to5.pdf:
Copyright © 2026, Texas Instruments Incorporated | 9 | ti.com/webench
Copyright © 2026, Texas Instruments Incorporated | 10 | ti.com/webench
